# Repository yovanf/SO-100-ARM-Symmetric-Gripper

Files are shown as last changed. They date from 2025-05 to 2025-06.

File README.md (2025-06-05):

**SO-100-YF Gripper**  
Version: 1  
Date: 14/05/2025  
Designer: Yovan Fowdar  
Organization: Mauritius AI Community  

Overview The SO-100-YF Gripper is a simple, symmetrical claw-style robotic gripper designed as an alternative to existing solutions. It is inspired by and based on the LeRobot project https://github.com/huggingface/lerobot.
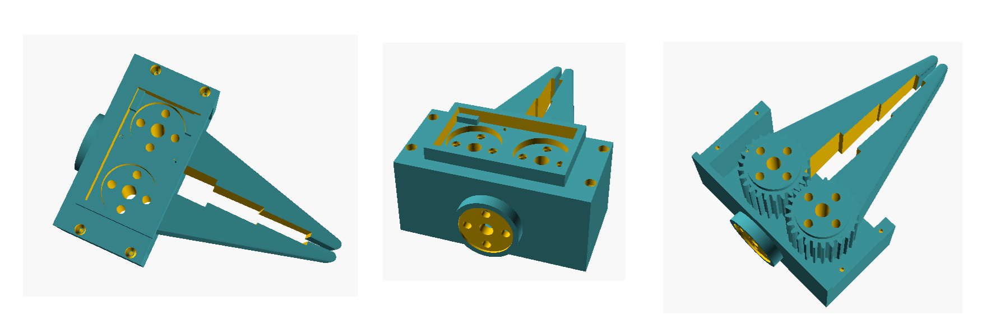
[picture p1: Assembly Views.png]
Gripper
  

**Demo Video**  https://www.youtube.com/shorts/Frp9GneYD9w

**This gripper features:**

Symmetrical claw closure for balanced gripping

Compatibility with ST3215 servo motors

A gear-driven mechanism that eliminates the need for additional fasteners (beyond those supplied with the servo)

The servo mounting plate is directly attached to one claw, and motion is transferred to the second claw via integrated gearing. For improved grip, it's recommended to line the claws with soft or spongy material.  

**Assembly Steps**  
1) Place the servo ST3215 on the Upper Case
2) Secure it with 2 small screws
3) On the left claw attach the servo metal plate and secure with 4 x M3 screws
4) Place the 2 claws in the Lower Case in a gripper closed position
5) Place the Upper Case on top of the Lower Case , making sure that gear of the plate slides in the servo shaft gear. (you might need to move the claws slightly)
6) Secure the Upper Case on the Lower Case with 4 small screws

**Features**

⚙️ Gear-based symmetrical claw movement

🧩 Lightweight and easy to integrate into robotic arms

**License**

This project is licensed under the MIT License. You are free to use, modify, and distribute it, with attribution to the original author.

STL Files & Licensing All STL files included in this repository are released under the MIT License, and are open to improvement, remixing, and customization. Community contributions are welcome—feel free to modify the design, adapt it for your use case, and submit pull requests.

**TODO**

Add a camera mount attachment to the servo motor body

Upload an assembly video  

Enhance the aesthetics with rounded corners

**Version 2 ** 
Please use file 4- Claw-Left- V2.stl  it is taller and is now more suitable to reach the ST-3125 servo metal drive disc, the holes for the screws have also been widen.

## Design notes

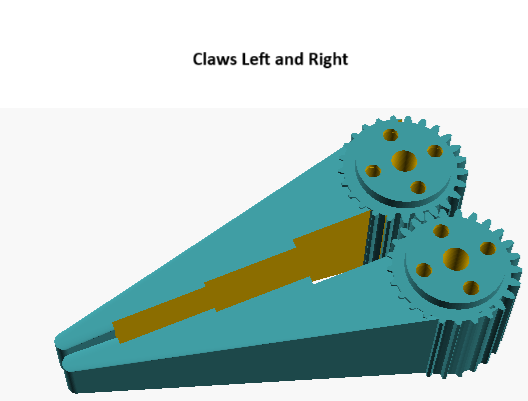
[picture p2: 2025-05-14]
Claws.png

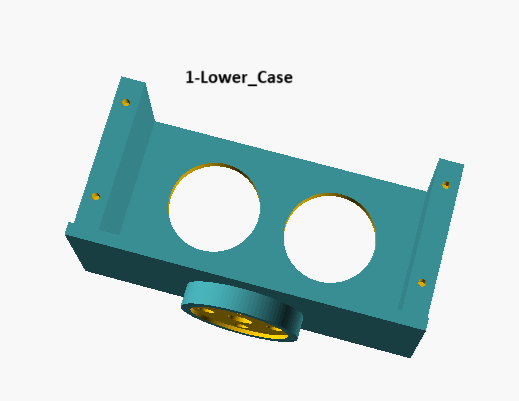
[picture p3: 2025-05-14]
Lower_Case.png

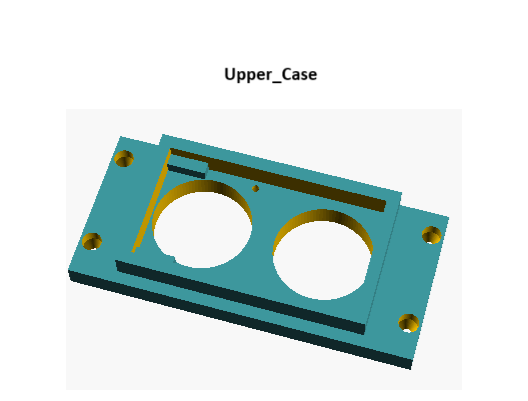
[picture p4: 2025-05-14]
Upper_case.png

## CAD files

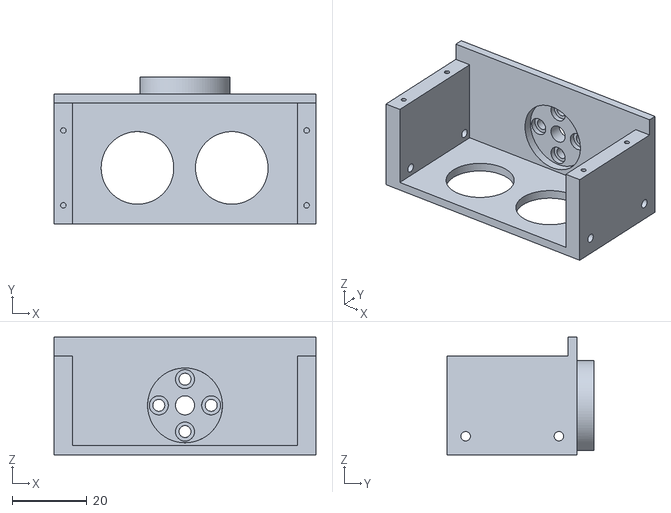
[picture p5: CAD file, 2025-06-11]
1-Lower_Case_mod.stl
70.0 x 39.3 x 31.5

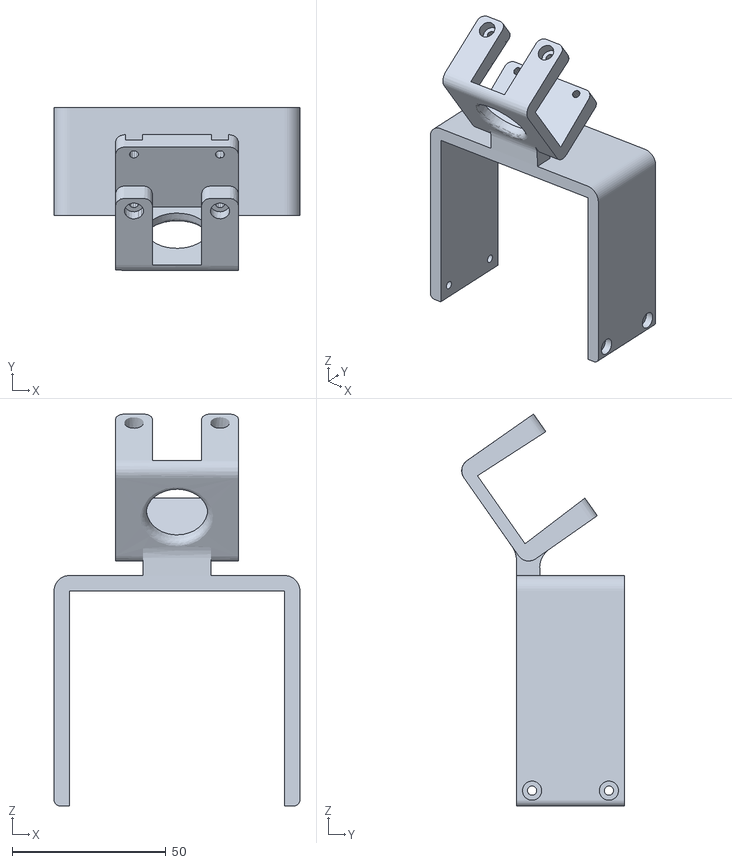
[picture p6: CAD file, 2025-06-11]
Camera_Mount.stl
80.0 x 52.9 x 127.6

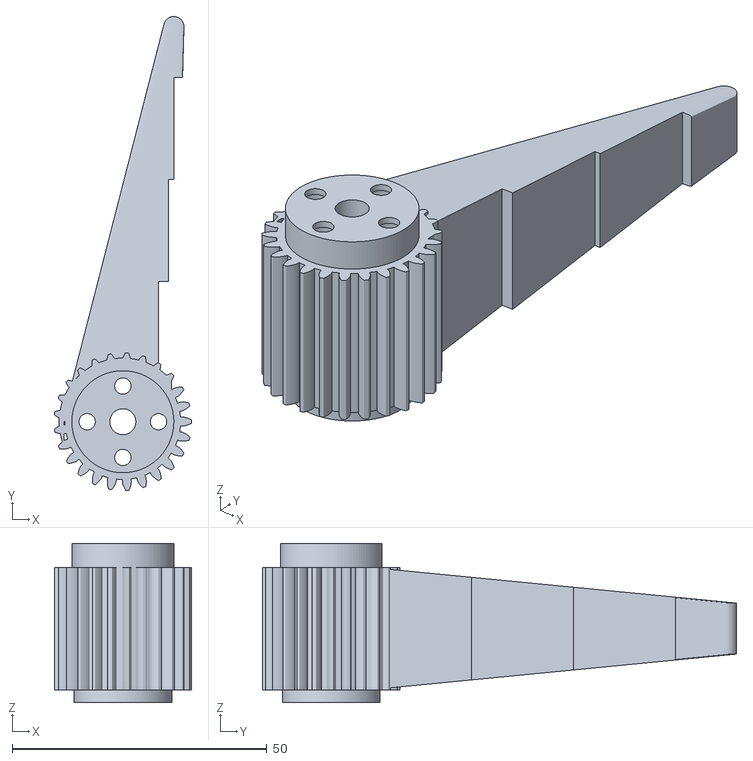
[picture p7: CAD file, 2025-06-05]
4- Claw-Left- V2.stl
26.9 x 93.0 x 31.2

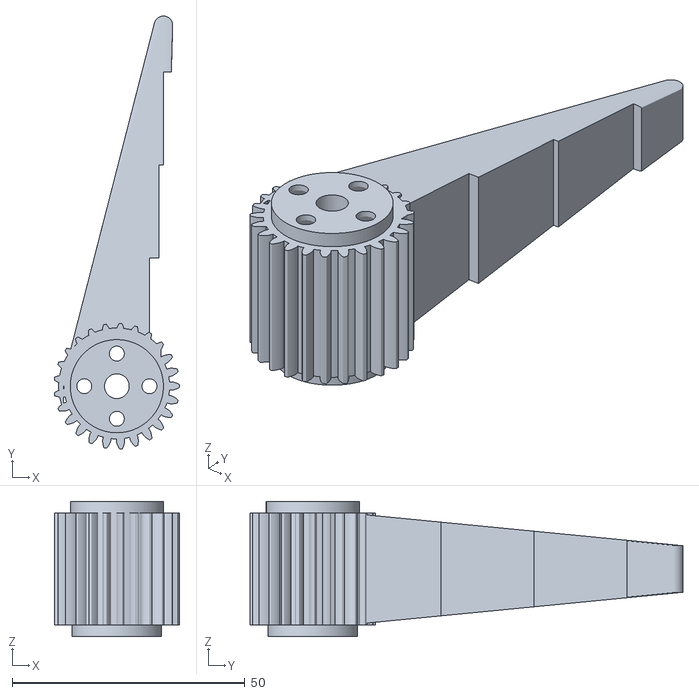
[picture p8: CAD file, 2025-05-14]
4-Claw-Left.stl
26.9 x 93.0 x 29.0

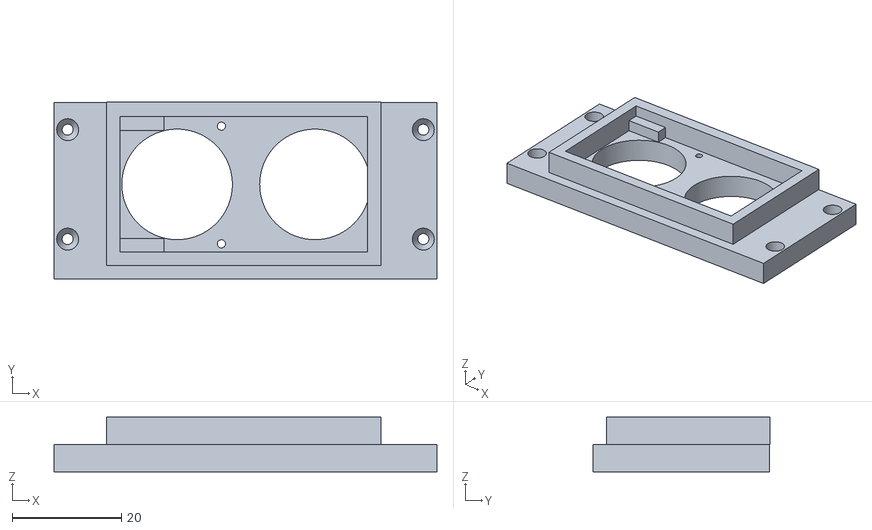
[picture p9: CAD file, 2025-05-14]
2-Upper_Case.stl
70.0 x 32.4 x 10.0

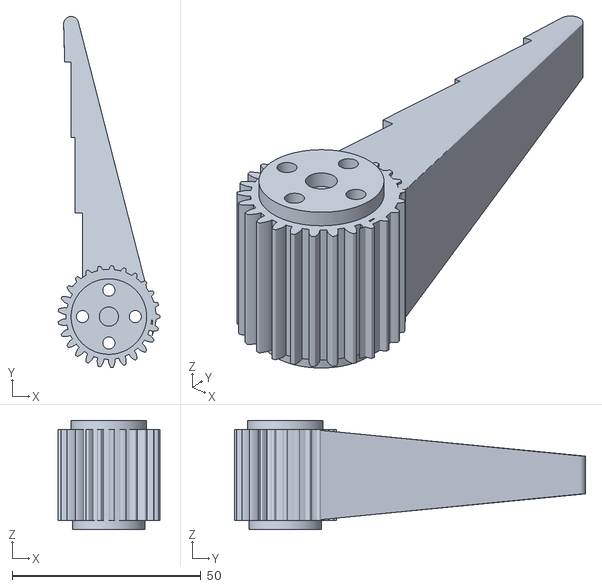
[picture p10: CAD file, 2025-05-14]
3-Claw-Right.stl
26.9 x 93.0 x 29.0

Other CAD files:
1-Lower_Case.stl

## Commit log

2025-06-05 Taller left claw
    The left claw center hub that connects to the servo disc has been made taller.
    [4- Claw-Left- V2.stl]
2025-06-05 Update README.md
    Better servo driven left claw
2025-06-09 Added modified lower case to support the camera mount as well as a new camera mount stl file
    [1-Lower_Case_mod.stl, Camera_Mount.stl]
